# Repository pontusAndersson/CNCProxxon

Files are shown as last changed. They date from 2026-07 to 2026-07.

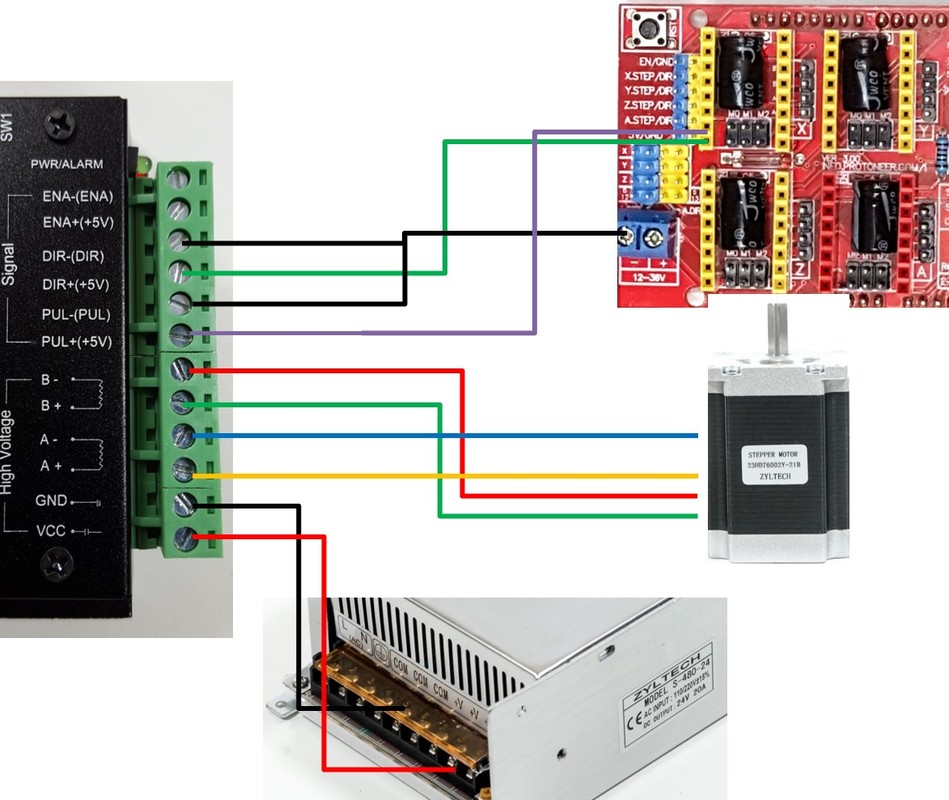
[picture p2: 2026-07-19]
tb6600-orig.jpg

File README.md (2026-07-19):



# Proxxon MF70 CNC-konvertering

Dokumentation av min ombyggnad av en Proxxon MF70 till en USB-styrd 3-axlig CNC-fräs, driven via Arduino + GRBL.

## Status

- [x] Mekanisk montering av axelkonsoler (X/Y/Z)
- [x] Elektronik vald och delvis inkopplad
- [x] GRBL flashat till Arduino, USB-anslutning verifierad
- [ ] TB6600-drivrutiner slutgiltigt inkopplade och strömtestade
- [ ] Steg/mm beräknat och konfigurerat i GRBL
- [ ] Första testfräsning

## Bakgrund / historik

Maskinen kördes ursprungligen med ett TB6560-baserat USB-styrkort (Mach3), men gav återkommande problem med tappade steg och drift över tid. Detta spårades till en kombination av:

- Ojämn USB-pulsgenerering i TB6560-kortet
- Undermålig strömreglering / överhettning i TB6560-chippet
- Eventuell mekanisk friktion (under utredning)

**Beslut:** Byta ut hela styrkedjan mot en mer robust lösning: Arduino Uno + GRBL-firmware + separata TB6600-drivrutiner, styrt via USB med UGS som g-kodsändare.

## Hårdvara

| Komponent | Detaljer |
|---|---|
| Maskin | Proxxon MF70, CNC-konverterad med axelkonsoler (X/Y/Z) |
| Stegmotorer | 3x Nema23 57x57x76mm, 1.8° step, 1.8Nm, 4A/fas |
| Drivrutiner | 3x TB6600, 4A, 9–42V, 2/4-fas |
| Styrkort | Arduino Uno + CNC Shield V3.0 (AZDelivery) |
| Nätaggregat | MW/MAX S-360-24, 24V 15A (360W) |
| Mjukvara (dator) | Arduino IDE (flashning), UGS (Universal G-code Sender) |
| Firmware | GRBL (installerat via Arduino IDE Library Manager) |

**Anmärkning om motorval:** Nema23 är egentligen överdimensionerat för en MF70 (Nema17 hade räckt och gett enklare montering), men motorerna ägdes redan innan projektet startade och används därför ändå. TB6600 klarar strömmen (4A/fas) utan problem.

**Anmärkning om spänning:** 24V PSU fungerar men ligger i lägsta laget för Nema23 (TB6600 tål upp till 42V). Kan ge minskat vridmoment vid höga hastigheter — eventuell framtida uppgradering till 36–48V PSU om det blir ett problem.

## Kopplingsschema

**Signalsida (Arduino/Shield → TB6600), per axel — common cathode (gemensam −, styr med +):**

| Shield-pin | TB6600-pin |
|---|---|
| X.STEP / Y.STEP / Z.STEP | PUL+ |
| X.DIR / Y.DIR / Z.DIR | DIR+ |
| GND (shield, delad mellan alla TB6600) | PUL− |
| GND (shield, samma) | DIR− |







**Effektsida (PSU → TB6600), delad buss:**

- PSU 24V+ → VCC på alla tre TB6600 (gemensam skruvplint)
- PSU GND → GND på alla tre TB6600 (gemensam skruvplint)
- Rekommenderad kabelarea: minst 1,5mm² på huvudmatning, 0,75–1mm² per TB6600-gren
- Säkring (10–15A) rekommenderad mellan PSU och fördelningsplint

**Motorsida (TB6600 → Motor):**

- TB6600 A+/A-/B+/B- → motorns två spolpar (identifiera med multimeter om ej märkta)
- Koppla aldrig loss motorkabel medan strömmen är på

**Viktigt:** Signal-GND (Arduino ↔ TB6600) och effekt-GND (PSU ↔ TB6600) hålls som separata kretsar för att undvika brus, trots att båda till slut delar samma nollpunkt i systemet.

## DIP-switchar (TB6600)

Ställ in **alla tre** drivrutiner likadant. Justera **alltid med strömmen av**.

Tabellerna nedan är avskrivna från etiketten på din TB6600 (kloner skiljer sig — lita på lådan).

**Val för detta projekt:** 1/8 microstep + 3.0 A (3.2 A peak).

| Switch | Läge | Betydelse |
|---|---|---|
| SW1 | **OFF** | |
| SW2 | **ON** | 1/8 microstep (1600 puls/varv) |
| SW3 | **OFF** | |
| SW4 | **OFF** | |
| SW5 | **ON** | 3.0 A (3.2 A peak) |
| SW6 | **OFF** | |

Kort: `OFF ON OFF ON OFF OFF`

### Referenstabeller (från din TB6600-etikett)

**Microstep (SW1–SW3):**

| Microstep | Puls/varv | SW1 | SW2 | SW3 |
|---|---|---|---|---|
| NC | — | ON | ON | ON |
| 1 (full) | 200 | OFF | ON | ON |
| 2/A | 400 | ON | OFF | ON |
| 2/B | 400 | OFF | OFF | ON |
| 4 | 800 | ON | ON | OFF |
| **8** | **1600** | **OFF** | **ON** | **OFF** |
| 16 | 3200 | ON | OFF | OFF |
| 32 | 6400 | OFF | OFF | OFF |

**Ström (SW4–SW6):**

| Ström | Peak | SW4 | SW5 | SW6 |
|---|---|---|---|---|
| 0.5 A | 0.7 A | ON | ON | ON |
| 1.0 A | 1.2 A | OFF | ON | ON |
| 1.5 A | 1.7 A | ON | OFF | ON |
| 2.0 A | 2.2 A | OFF | OFF | ON |
| 2.5 A | 2.7 A | ON | ON | OFF |
| 2.8 A | 2.9 A | OFF | ON | OFF |
| **3.0 A** | **3.2 A** | **ON** | **OFF** | **OFF** |
| 3.5 A | 4.0 A | OFF | OFF | OFF |

Vald microstepping måste matcha GRBL `$100/$101/$102` (steg/mm).



## Mjukvaruinstallation

1. Installera [Arduino IDE](https://www.arduino.cc/en/software)
2. I Arduino IDE: **Sketch → Include Library → Manage Libraries**, sök på "grbl", installera
3. **File → Examples → grbl → grblUpload**, välj rätt board (Uno) och port, klicka Upload
   - Varning om minnesanvändning (~92% flash, ~79% RAM) är normalt för GRBL på Uno och kan ignoreras
4. Installera [UGS (Universal G-code Sender)](https://winder.github.io/ugs_website/) på styrdatorn
5. Anslut Arduino via USB, öppna UGS, välj rätt port, baudrate **115200**, klicka Connect
   - Verifierat: GRBL svarar med välkomstmeddelande `Grbl x.xx ['$' for help]`

## Kända problem / felsökning

**Tappade steg / drift över tid (ursprungsproblem med TB6560):**
Möjliga orsaker i prioritetsordning: mekanisk bindning, understäld ström på drivrutin, för hög acceleration i mjukvarukonfig, elektriskt brus i kablage, överhettning i drivsteg, felmatchad microstepping mellan drivrutin och mjukvarukonfig. Förväntas minska rejält med TB6600 + GRBL jämfört med tidigare TB6560/Mach3-kombo.

## Återstående arbete

- [ ] Ställ in DIP-switchar på varje TB6600 enligt sektionen ovan (`OFF ON OFF ON OFF OFF`)
- [ ] Beräkna och sätt `$100/$101/$102` (steg/mm) i GRBL utifrån kulskruvens stigning och 1/8 microstep (1600 puls/varv)
- [ ] Koppla in ändlägesbrytare (shieldens X+/X-/Y+/Y-/Z+/Z- mot GND)
- [ ] Första provkörning med låg hastighet/acceleration, öka stegvis
- [ ] Om drift kvarstår: överväg 36–48V PSU-uppgradering för mer marginal på Nema23

## CNC Shield V3.0

Expansionskort för Arduino Uno R3/R4 som bryter ut GRBL:s steg-/riktningssignaler till upp till fyra axlar. I detta projekt används shielden **utan** inbyggda A4988/DRV8825 — istället tas STEP/DIR/GND ut till externa TB6600-drivrutiner.

### Specifikationer

| | |
|---|---|
| Kompatibilitet | Arduino Uno R3/R4 |
| Drivrutinssocklar | 4 (X, Y, Z, A) |
| Tänkta drivrutiner | A4988 / DRV8825 *(används ej här)* |
| Microstepping | Via jumpers på shielden *(irrelevant med TB6600 — ställs på drivrutinen)* |
| Ändlägen | X+/X−, Y+/Y−, Z+/Z− |
| Övrigt | Spindle enable/direction, coolant |
| Motor matning (vid onboard-drivrutiner) | Extern DC 12–36 V |

### Användning i detta projekt

- Arduino Uno + GRBL ger pulser via USB (UGS)
- Shielden ger praktiska anslutningspunkter för STEP, DIR och GND per axel
- Motorström går **inte** via shielden — den matas direkt PSU → TB6600

## Resurser

- GRBL: https://github.com/gnea/grbl
- UGS: https://winder.github.io/ugs_website/
- Arduino IDE: https://www.arduino.cc/en/software

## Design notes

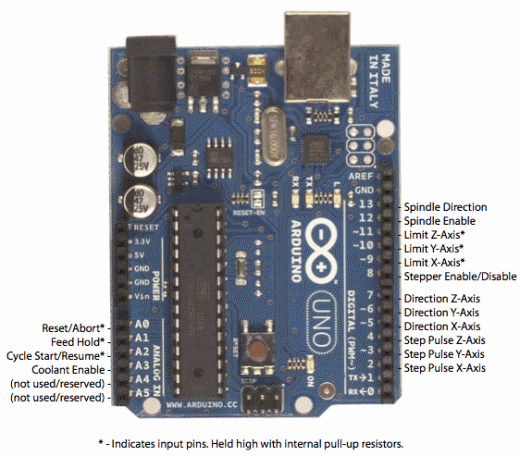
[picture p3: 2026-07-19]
Uno expl.png

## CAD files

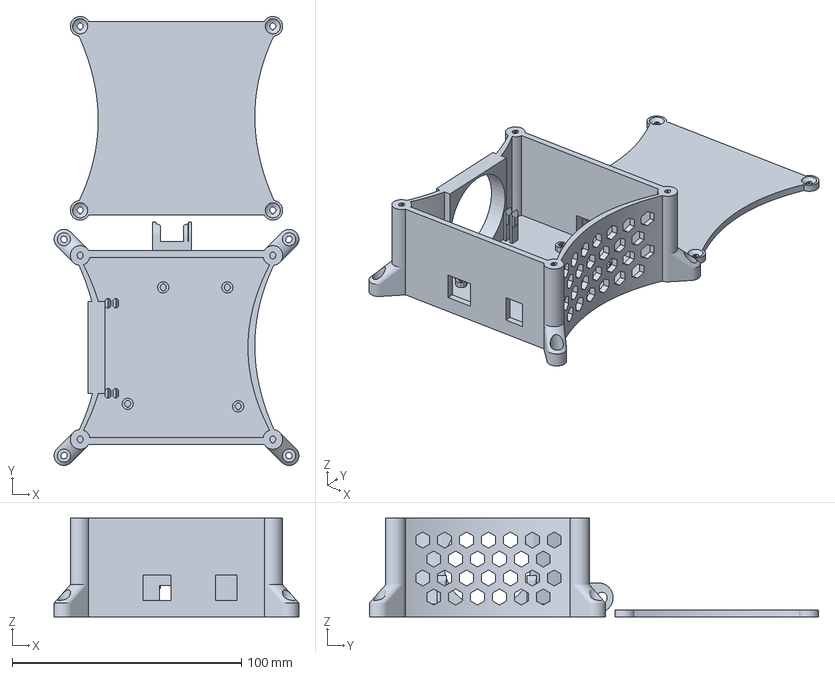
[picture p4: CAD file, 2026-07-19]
CNCarduinoshield.3mf
106.8 x 196.0 x 43.0 mm

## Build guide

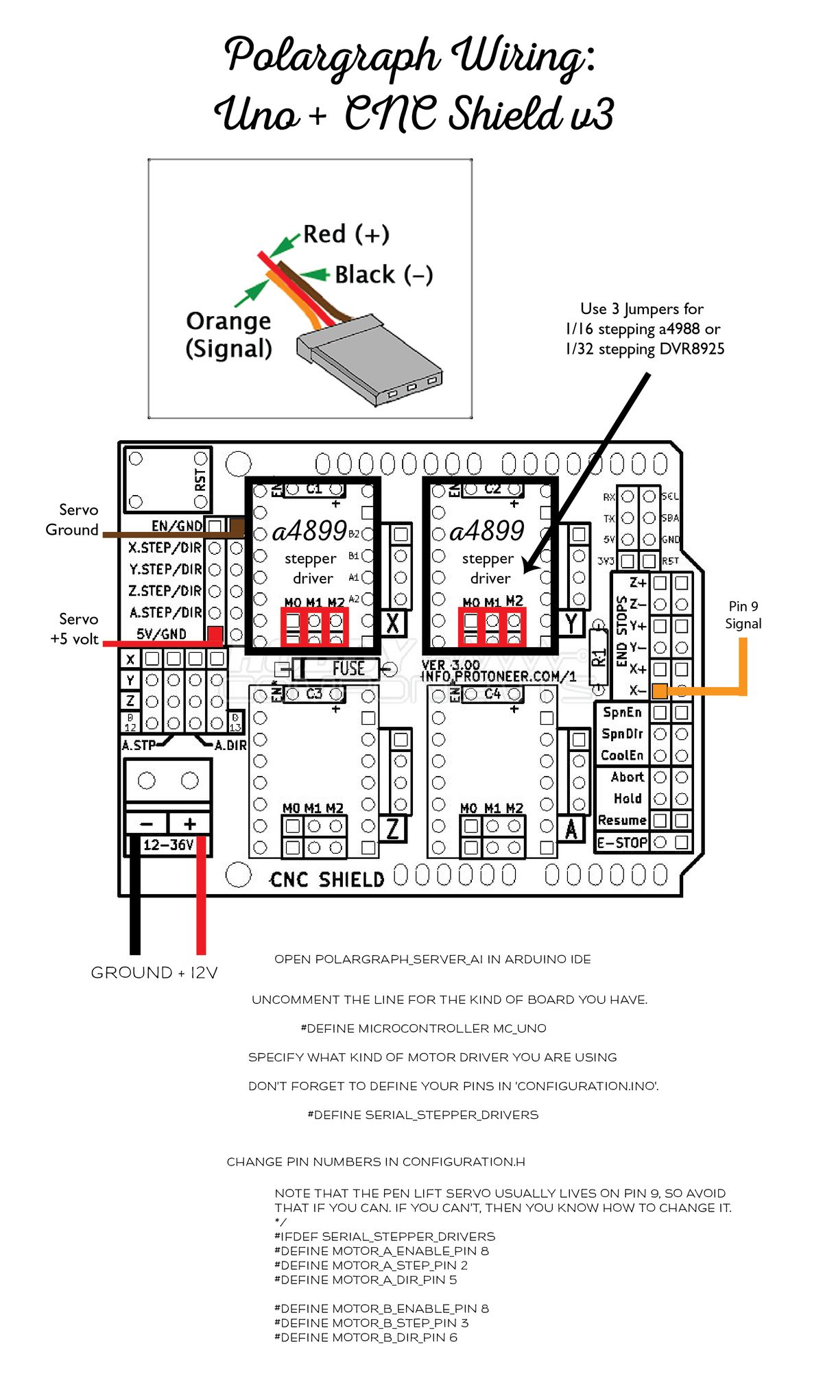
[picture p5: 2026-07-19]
Polargraph Wiring Uno+ CNC shield v3.jpg
